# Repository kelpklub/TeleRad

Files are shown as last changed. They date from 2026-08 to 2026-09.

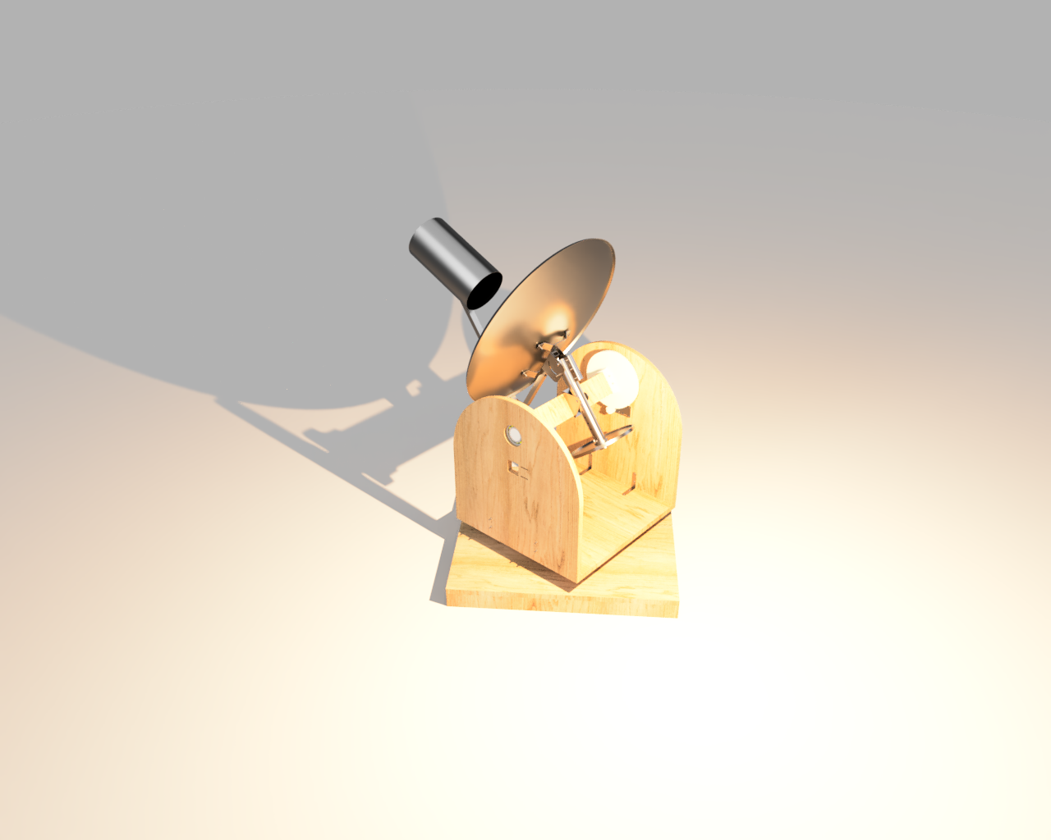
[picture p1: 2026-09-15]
TeleRad-Render.png

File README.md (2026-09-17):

# TeleRad-A radio telescope  
###       
NOTE: This project is currently in its design phase. No physical prototype has been made yet.  
A radio telescope mounted on an two axis alt-azimuth motorized mount for observing radio phenomenon.  
# About TeleRad  
I've always loved stargazing as a kid back in My rural Village . My love for the cosmos hasn't decreased , in fact it has increased manyfold. Alas ! Now i live in the In the Urban Area with light bleeding out every star . Even in my village I cant stargaze anymore.  
But is a few thousand lightbulbs going to stop me from observing the Night sky.  
NO , IT WILL NOT.  
TL;DR- I decided Viewing it in a diffrent ElectroMagnetic Spectrum would prove to be better as theres not as much radio pollution than light pollution. 
# What I Learned  
- Mechanical Design
- Embedded System
- Planning And Designing
- Communication protocol
- Optimizing Costs and Trade-offs
- Will Probs learn More during the building phase.

# Overview 
The Radio telescope will be made up of two systems.  
- Esp32 powered dual axis mount  
 (An Esp32 will control two stepper motors which will motorize two axes of the mount. The mount will move in a snake scan pattern across the sky.)
- Radio reciever  
  (An parabolic satallite ~75cm in diameter dish will will feed signal into a Low Noise Amplifier which goes through a Software Defined Radio dongle into a computer where it will be processed and converten into a 2d image map)  
## Bill of Materials
Heres everything needed for this project. [Bill Of Materials](BOM.csv)  
| Name | Quantity | Per Unit Cost (INR) | Total Cost (INR) | Total Cost (USD) | Link |
|---|---:|---:|---:|---:|---|
| Nema 17 Stepper Motor | 2 | 1109 | 2218 | 23.35 | [Link](https://robu.in/product/42hs60-1684-nema17-7-2kg-cm-stepper-motor-round-type/) |
| Nema 17 Mount Straight | 2 | 201 | 402 | 4.23 | [Link](https://robu.in/product/easymech-bracket-for-nema-17-stepper-motor-2/) |
| DRV8825 Stepper motor driver | 2 | 96 | 192 | 2.02 | [Link](https://robu.in/product/drv8825-stepper-motor-driver-aluminum-heat-sink-good-quality/) |
| 6008 Ball Bearing | 2 | 179 | 358 | 3.77 | [Link](https://www.amazon.in/gp/product/B08LPR978X/ref=ox_sc_act_title_7?smid=A1ATPDR7BUKQN6&th=1) |
| m3 x4mm brass inserts | 4 | 4.4 | 17.6 | 0.2 | [Link](https://onlyscrews.in/products/m3-x-4mm-3d-printing-brass-threaded-inserts-dia-3mm-length-4mm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) |
| m3 x6 mm screws | 14 | 1.2 | 16.8 | 0.18 | [Link](https://onlyscrews.in/products/hex-allen-csk-m3-x-6-screw-pack-of-20?variant=48591246098745) |
| M4 Hex Nut | 37 | - | - | - | Self Funded |
| M4 Bolt 35mm | 14 | - | - | - | Self Funded |
| M4 Bolt 25mm | 4 | - | - | - | Self Funded |
| M4 Bolt 40mm | 2 | - | - | - | Self Funded |
| Limit switches | 2 | 15 | 30 | 0.4 | [Link](https://robu.in/product/limit-switch-kv-05/) |
| 3m USB A to USB A | 1 | 399 | 399 | 4.2 | [Link](https://www.amazon.in/Storite-3-0-Extension-Transfer-Keyboard/dp/B00OFM6PFS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) |
| 22 Gague jumper wire | 2 | 149 | 298 | 3.14 | [Link](https://www.amazon.in/gp/product/B0B4WPX449/ref=ox_sc_act_title_2?smid=AJ6SIZC8YQDZX&psc=1) |
| Coaxial Cable | 1 | 294 | 294 | 3.09 | [Link](https://www.amazon.in/gp/product/B08254RHT3/ref=ox_sc_act_title_6?smid=A3G972E7L8N6MV&psc=1) |
| SMA Edge connector for DIY feed | 1 | 99 | 99 | 1.1 | [Link](https://www.amazon.in/Panel-Straight-Connector-Coaxial-Adapter/dp/B0965PSMSW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) |
| RTL SDR V3 | 1 | 7678 | 7678 | 80.82 | [Link](https://www.amazon.in/gp/product/B0BMKB3L47/ref=ox_sc_act_image_1?smid=A1YZ9MMK17G6RH&th=1) |
| Low Noise Amplifier | 1 | 205 | 205 | 2.16 | [Link](https://robu.in/product/0-1-2000mhz-rf-wideband-amplifier-gain-30db-low-noise-amplifier-lna-board-module/) |
| ESP 32 | 1 | 549 | 549 | 5.78 | [Link](https://www.amazon.in/gp/product/B0D6GDV77P/ref=ox_sc_act_title_4?smid=AJ6SIZC8YQDZX&psc=1) |
| DC-DC 12V-3.3V | 1 | 49 | 49 | 0.52 | [Link](https://robu.in/product/dc-dc-voltage-converter-multi-output-power-supply-module-12v-3-3v5v12v/) |
| 12V 5A powersupply | 1 | 449 | 449 | 4.73 | [Link](https://robu.in/product/orange-ac-100-240v-to-dc-12v-5a-60w-power-adapter/) |
| Perf Board | 2 | 118 | 236 | 2.48 | [Link](https://www.amazon.in/gp/product/B09ZB4W17X/ref=ox_sc_act_title_1?smid=A31PUIOPHJ56Y3&psc=1) |
| 100 uF Capacitors | 5 | 2.36 | 11.8 | 0.2 | [Link](https://robu.in/product/100-uf-35v-through-hole-electrolytic-capacitor-dip-pack-of-10/) |
| 100nF Capacitor | 10 | 1.25 | 12.5 | 0.2 | [Link](https://robu.in/product/100nf-50v-disc-capacitor/) |
| 5x20 Cartridge Fuse 4A | 5 | 36 | 144 | 1.51 | [Link](https://robu.in/product/0239004-mxp-littelfuse-0239004-mxp-fuse-cartridge-time-delay-4-a-125-v-5mm-x-20mm-0-2-x-0-79-slo-blo-239/) |
| 5x20 Cartridge Fuse Holder | 1 | 30 | 30 | 0.31 | [Link](https://robu.in/product/0239004-mxp-littelfuse-0239004-mxp-fuse-cartridge-time-delay-4-a-125-v-5mm-x-20mm-0-2-x-0-79-slo-blo-239/) |
| allen key set | 1 | 200 | 200 | 2.09 | [Link](https://onlyscrews.in/products/allen-key-mm-set-m1-5-to-m10-chrome-vanadium-steel?variant=49975496671545) |
| 3D Prints | 1 | 2867.40 | 2867.40 | 30 | #printing-legion |
| **Total** | | | | **151.11** | |
## CAD  
The Basic Cad design Assembly Of the mount can be found at [TeleRad Assembly](CAD/Components%20STEP/Assembly/Assembly.step)
TeleRad

The Mount utilizes Gears to increase torque.
Screenshot (7)  
## Gears  
### Gear Ratio
The gear Ratios for both axes are as follows :-  
For The Altitude Rotation - Input gear teeth = 16T ; Output gear teeth = 128T  
For The Azimuth  Rotation - Input gear teeth = 24T ; Output gear teeth = 72T  
### 3D printing  
The STL files to be present are int [3D Print STL](CAD/3D%20Print%20STL/)
## Basic Wiring  
The wiring is as follows:-  
TeleRad-Schematic_diagram

**MICROSTEPPING** - The M2 pin of both driver boards are connected to 3.3v of esp32 to set microstepping to 1/16 microstepping following the documentation of the drv8825 board.  
microsteps-drv8825-snip  
**DRV8825 BOARD PROTECTION** - A 100µF Capacitor And 100nF Capacitor are wired across VMOT and GND to stabalize VMOT and Supress high frequency Noise.  
**POWER SUPPLY** - An external powersupply of 12V is required for the two DRV8825 connected to VMOT of both driver.  
## Homing  
At Setup both motots will move in -x and -y direction till the it hits its respective limiting switch. When it does it will Mark that position as origin of that axis.After both axes have been calibrated it will rely on step counting for its current position.  
# Software  
TeleRad consists of two software components  
## ESP32 Firmware- Acts as a Motion Controller.  
It handles 
- Stepper Motor Control.
- Homing.
- Position Tracking.
- Serial Command Processing.
## Python firmware 
- ESP32 Communication
- Mount Control
- SDR control
- Radio Measurments
- Scanning
# Setup  
## Hardware 
- Assemble the Mount.
- uhhh (More Detailed Instructions will be given after i build the mount.)
## Software  
### ESP32  
1.Install Arduino IDE 
2.Install ESP32 Board Support  
3.Install AccelStepper Library for Arduino IDE  
4.Open Firmware/ESP-32/ESP-32.ino in Arduino IDE  
5.Connect ESP32 with a USB data cable.  
6.Compile the .ino and uploAd it to the ESP.  
7.Test The serial connection by sending "PING" using Serial Moniter.  
### Python 
Clone the Repository and install the Python dependencies.  
cd Firmware/python  
pip install -e .  
Verify Installation wit "telerad --help"  
# Usage  
## Python cli  
- Check Mount Status
  ```bash
  telerad mount status
- Check curremt Position
  ```bash
  telerad mount position
- Home Mount
  ```bash
  telerad mount home  
- Move the mount
  ```bash
  telerad mount move 90 45  
- Move Mount relavtive to its current position
  ```bash
  telerad mount rel 10 -5  
- Scan
  ```bash
  telerad scan start --from 20,30 --to 100,60 --step 1 
NOTE: for Scan the coordinates are opposites corners of a rectangle. the bottom-left and top-right.
- Park the mount
  ```bash
  telerad mount park
- Stop the mount
  ```bash
  telerad mount stop
# AI Declaration  
AI helped with creation of the Firmware Of this project.

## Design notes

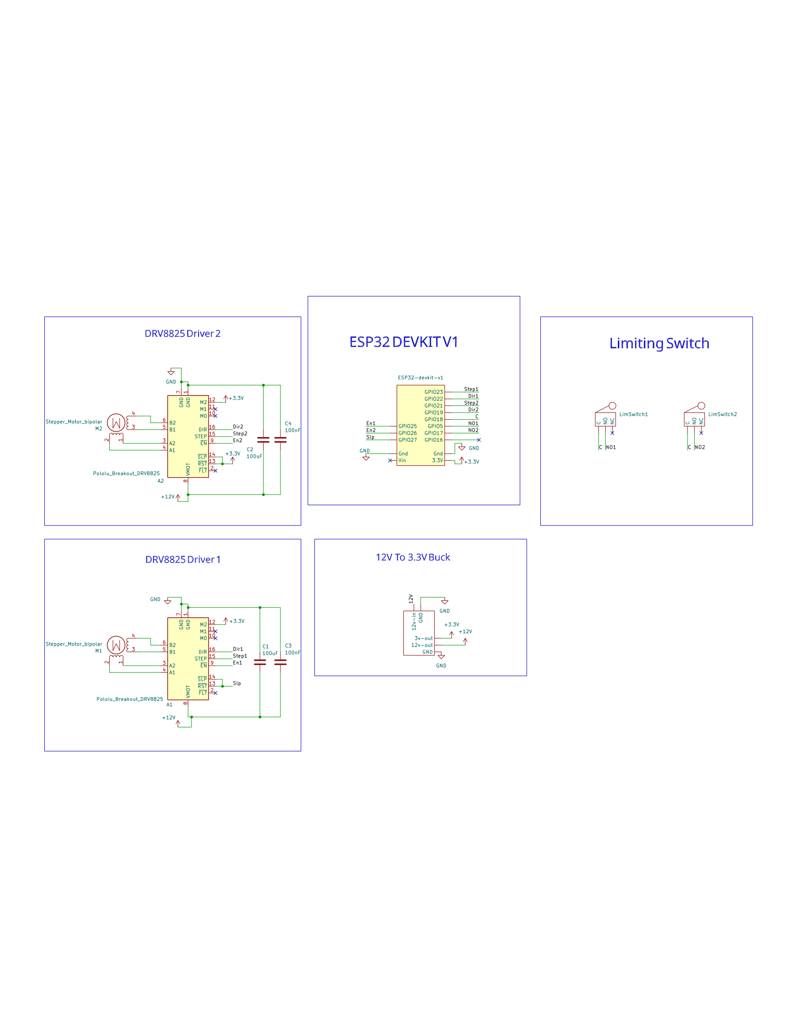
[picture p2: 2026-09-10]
TeleRad-Schematic_diagram.png

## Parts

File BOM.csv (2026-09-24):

Name | Quantity | Per Unit Cost (INR) | Total Cost (INR) | Total Cost (USD) | Link
Nema 17 Stepper Motor | 2 | 1109 | 2218 | 23.35 | https://robu.in/product/42hs60-1684-nema17-7-2kg-cm-stepper-motor-round-type/
Nema 17 Mount Straight | 2 | 201 | 402 | 4.23 | https://robu.in/product/easymech-bracket-for-nema-17-stepper-motor-2/
DRV8825 Stepper motor driver | 2 | 96 | 192 | 2.02 | https://robu.in/product/drv8825-stepper-motor-driver-aluminum-heat-sink-good-quality/
6008 Ball Bearing | 2 | 179 | 358 | 3.77 | https://www.amazon.in/gp/product/B08LPR978X/ref=ox_sc_act_title_7?smid=A1ATPDR7BUKQN6&th=1
m3 x4mm brass inserts | 4 | 4.4 | 17.6 | 0.2 | https://onlyscrews.in/products/m3-x-4mm-3d-printing-brass-threaded-inserts-dia-3mm-length-4mm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
m3 x6 mm screws | 20 | 1.2 | 16.8 | 0.18 | https://onlyscrews.in/products/hex-allen-csk-m3-x-6-screw-pack-of-20?variant=48591246098745
M4 Hex Nut | 37 | - | - | - | Self Funded
M4 Bolt 35mm | 14 | - | - | - | Self Funded
M4 Bolt 25mm | 4 | - | - | - | Self Funded
M4 Bolt 40mm | 2 | - | - | - | Self Funded
Limit switches | 2 | 15 | 30 | 0.4 | https://robu.in/product/limit-switch-kv-05/
3m USB A to USB A | 1 | 399 | 399 | 4.2 | https://www.amazon.in/Storite-3-0-Extension-Transfer-Keyboard/dp/B00OFM6PFS
22 Gague jumper wire | 2 | 149 | 298 | 3.14 | https://www.amazon.in/gp/product/B0B4WPX449/ref=ox_sc_act_title_2?smid=AJ6SIZC8YQDZX&psc=1
Coaxial Cable | 1 | 294 | 294 | 3.09 | https://www.amazon.in/gp/product/B08254RHT3/ref=ox_sc_act_title_6?smid=A3G972E7L8N6MV&psc=1
SMA Edge connector for DIY feed | 1 | 99 | 99 | 1.1 | https://www.amazon.in/Panel-Straight-Connector-Coaxial-Adapter/dp/B0965PSMSW
RTL SDR V3 | 1 | 7678 | 7678 | 80.82 | https://www.amazon.in/gp/product/B0BMKB3L47/ref=ox_sc_act_image_1?smid=A1YZ9MMK17G6RH&th=1
Low Noise Amplifier | 1 | 205 | 205 | 2.16 | https://robu.in/product/0-1-2000mhz-rf-wideband-amplifier-gain-30db-low-noise-amplifier-lna-board-module/
ESP 32 | 1 | 549 | 549 | 5.78 | https://www.amazon.in/gp/product/B0D6GDV77P/ref=ox_sc_act_title_4?smid=AJ6SIZC8YQDZX&psc=1
DC-DC 12V-3.3V | 1 | 49 | 49 | 0.52 | https://robu.in/product/dc-dc-voltage-converter-multi-output-power-supply-module-12v-3-3v5v12v/
12V 5A powersupply | 1 | 449 | 449 | 4.73 | https://robu.in/product/orange-ac-100-240v-to-dc-12v-5a-60w-power-adapter/
Perf Board | 2 | 118 | 236 | 2.48 | https://www.amazon.in/gp/product/B09ZB4W17X/ref=ox_sc_act_title_1?smid=A31PUIOPHJ56Y3&psc=1
100 uF Capacitors | 5 | 2.36 | 11.8 | 0.2 | https://robu.in/product/100-uf-35v-through-hole-electrolytic-capacitor-dip-pack-of-10/
100nF Capacitor | 10 | 1.25 | 12.5 | 0.2 | https://robu.in/product/100nf-50v-disc-capacitor/
5x20 Cartridge Fuse 4A | 5 | 36 | 144 | 1.51 | https://robu.in/product/0239004-mxp-littelfuse-0239004-mxp-fuse-cartridge-time-delay-4-a-125-v-5mm-x-20mm-0-2-x-0-79-slo-blo-239/
5x20 Cartridge Fuse Holder | 1 | 30 | 30 | 0.31 | https://robu.in/product/0239004-mxp-littelfuse-0239004-mxp-fuse-cartridge-time-delay-4-a-125-v-5mm-x-20mm-0-2-x-0-79-slo-blo-239/
allen key set | 1 | 200 | 200 | 2.09 | https://onlyscrews.in/products/allen-key-mm-set-m1-5-to-m10-chrome-vanadium-steel?variant=49975496671545
3D Prints | 1 | 2867.4 | 2867.4 | 30 | -
18 mm Plywood | 1 | 1200 | 1200 | 12.5 | Local Hardware Store
 |  |  |  | 188.98

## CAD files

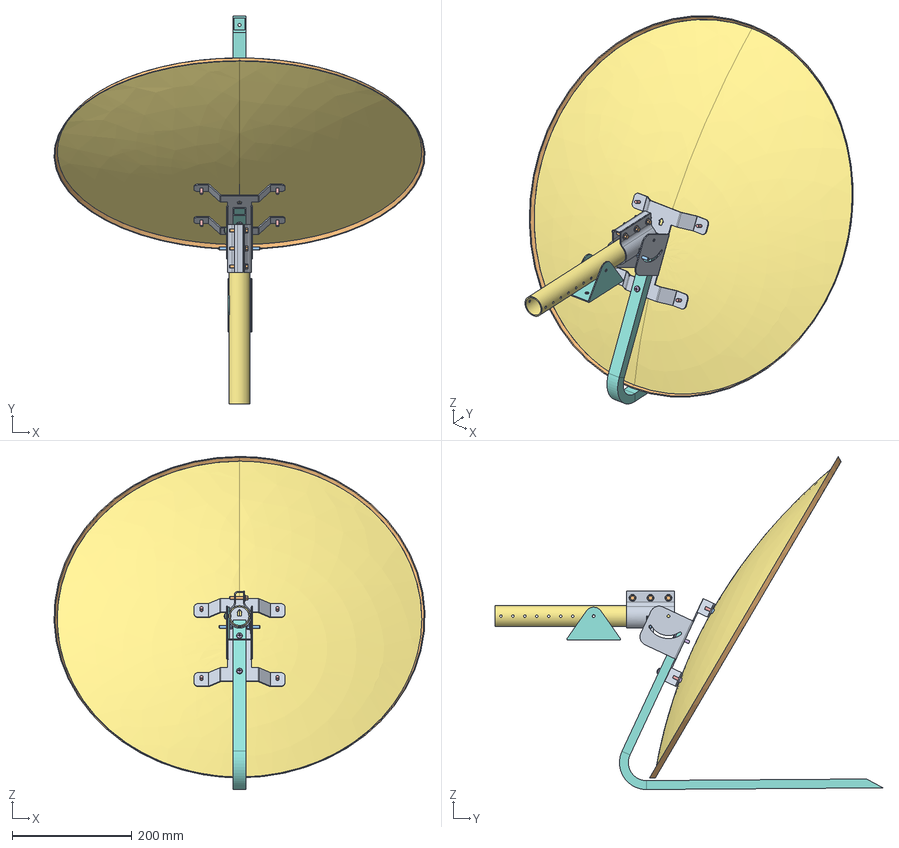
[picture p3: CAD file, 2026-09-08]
CAD/Components STEP/MISC/satellite_assembly.step
620.2 x 648.7 x 556.9 mm
wall_clamp
angle_bracket
dish
main_rod
reciver_rod
support_clamp x 2
tightening_fit
hex flange bolt small_iso_ISO 4162 - M5 x 25 x 25-N x 3
hex flange bolt small_iso_ISO 4162 - M5 x 50 x 50-N x 2
hex flange bolt small_iso_ISO 4162 - M5 x 16 x 16-N x 2
pan head cross recess screw_iso_ISO 7045 - M5 x 8 - Z - 8N
pan head cross recess screw_iso_ISO 7045 - M5 x 16 - Z - 16N x 4
pan head cross recess screw_iso_ISO 7045 - M5 x 25 - Z - 25N x 2
hex flange nut gradea_iso_ISO - 4161 - M5 - N x 13
wall_clamp_1

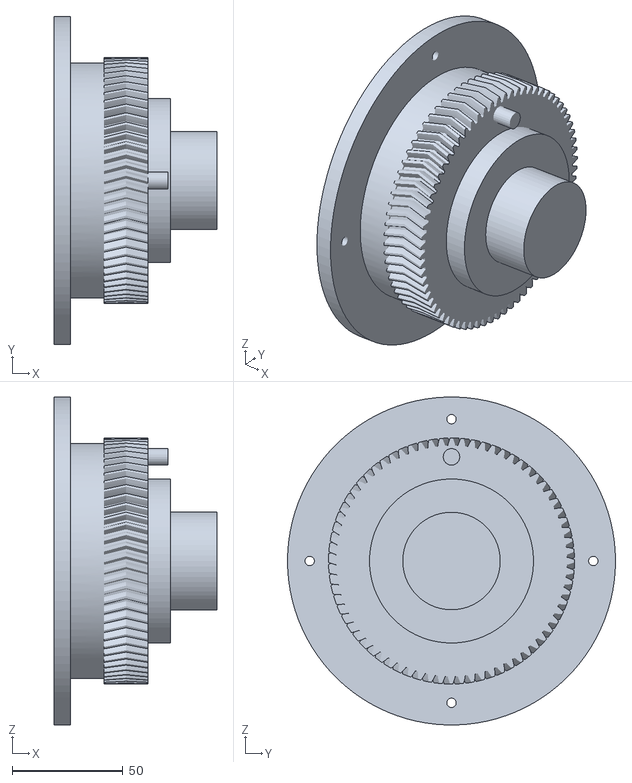
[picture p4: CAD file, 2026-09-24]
CAD/3D Print STL/Azimuth output gear 72T.stl
73.5 x 148.0 x 147.9

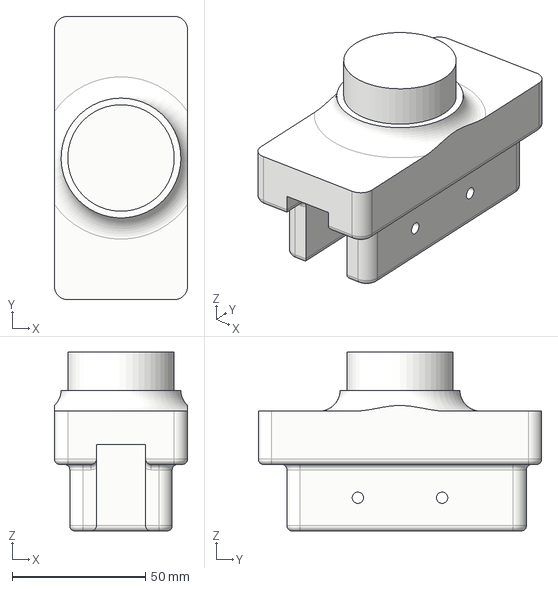
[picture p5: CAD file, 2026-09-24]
CAD/Components STEP/Altitude/Altitude Bearing to plank connector.step
50.0 x 106.5 x 67.2 mm

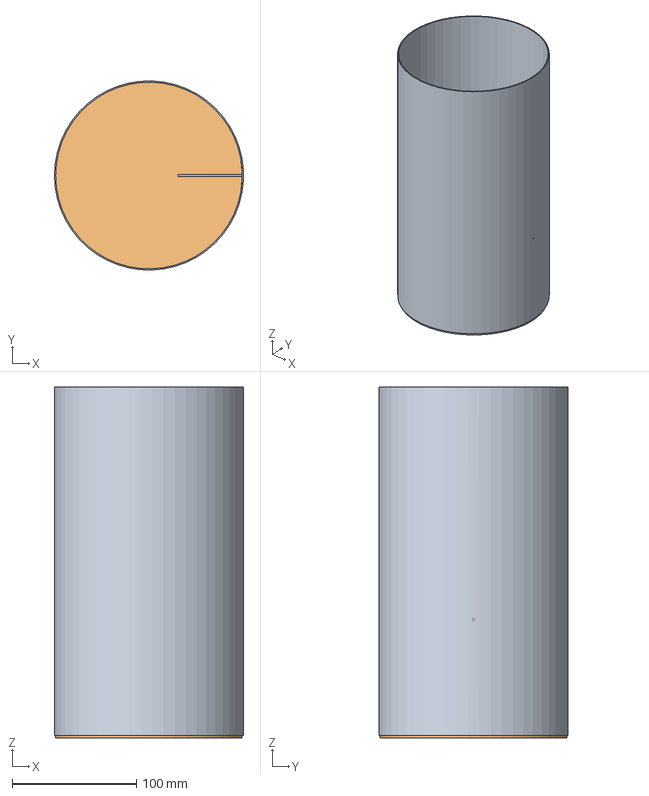
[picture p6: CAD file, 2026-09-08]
CAD/Components STEP/MISC/Caantenna feed.step
152.0 x 151.9 x 282.1 mm

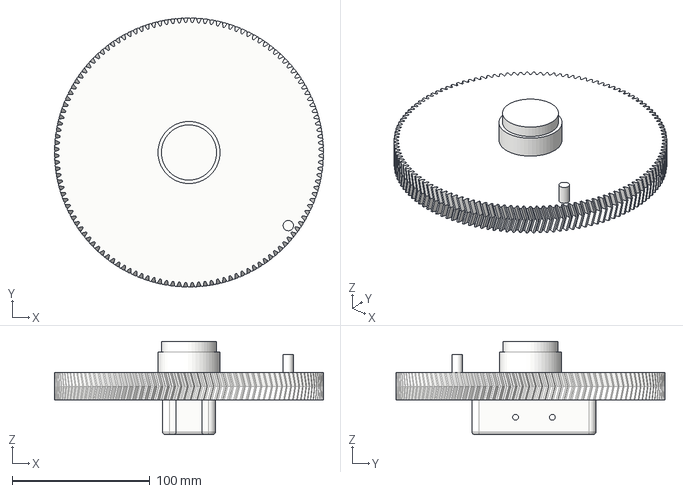
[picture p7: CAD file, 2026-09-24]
CAD/Components STEP/Altitude/Altitude Output gear 128T.step
195.0 x 195.0 x 67.5 mm

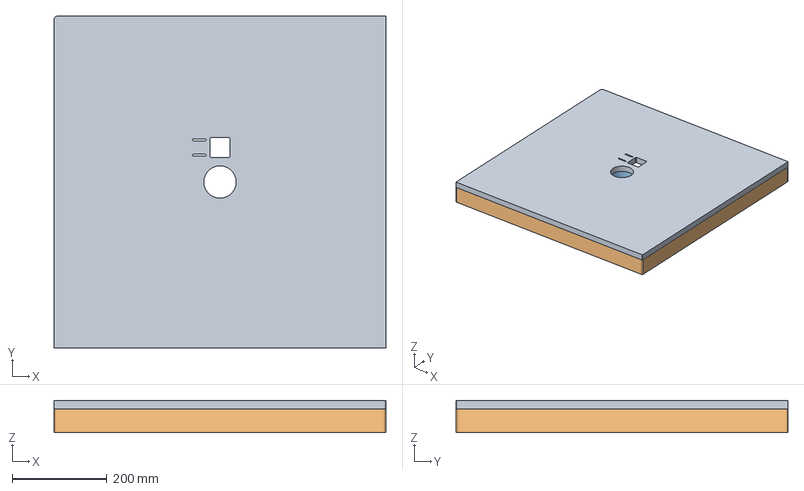
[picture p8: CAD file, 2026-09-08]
CAD/Components STEP/Azimuth/BasePlate.step
700.0 x 700.0 x 68.0 mm

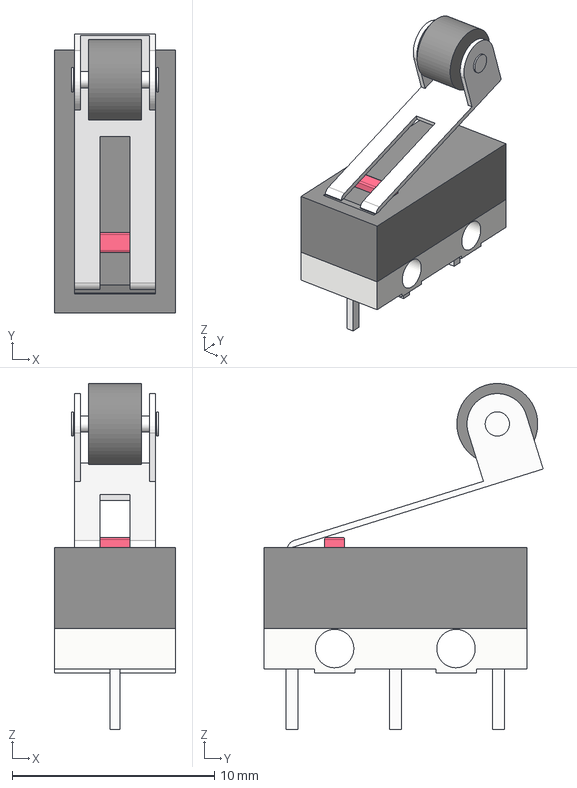
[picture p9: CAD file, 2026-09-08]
CAD/Components STEP/MISC/limit switch.step
6.00 x 13.8 x 17.1 mm

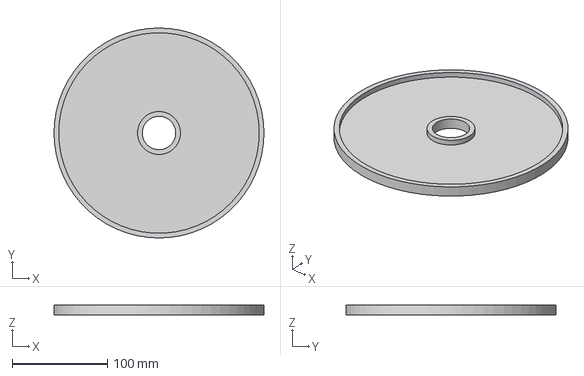
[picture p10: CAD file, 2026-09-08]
CAD/Components STEP/Altitude/Altitude Counterweight.step
220.0 x 220.0 x 10.0 mm

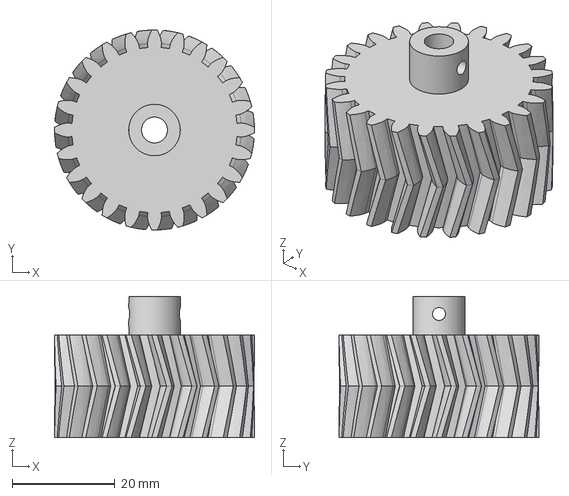
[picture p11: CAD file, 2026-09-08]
CAD/Components STEP/Azimuth/Azimuth input gear 24T.step
39.0 x 39.0 x 27.5 mm

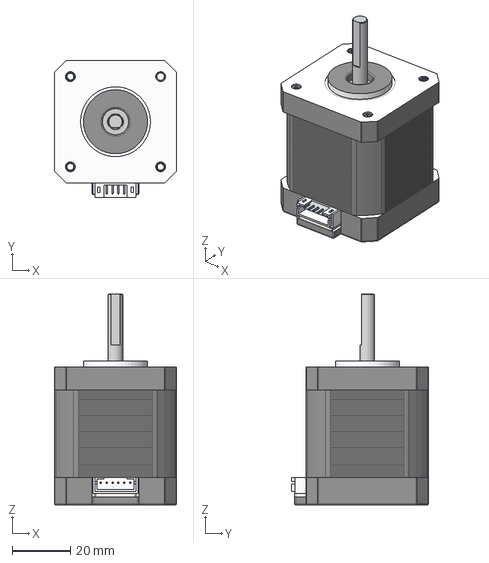
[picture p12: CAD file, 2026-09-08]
CAD/Components STEP/MISC/Nema17.step
42.0 x 47.0 x 72.5 mm
Motor
Shaft

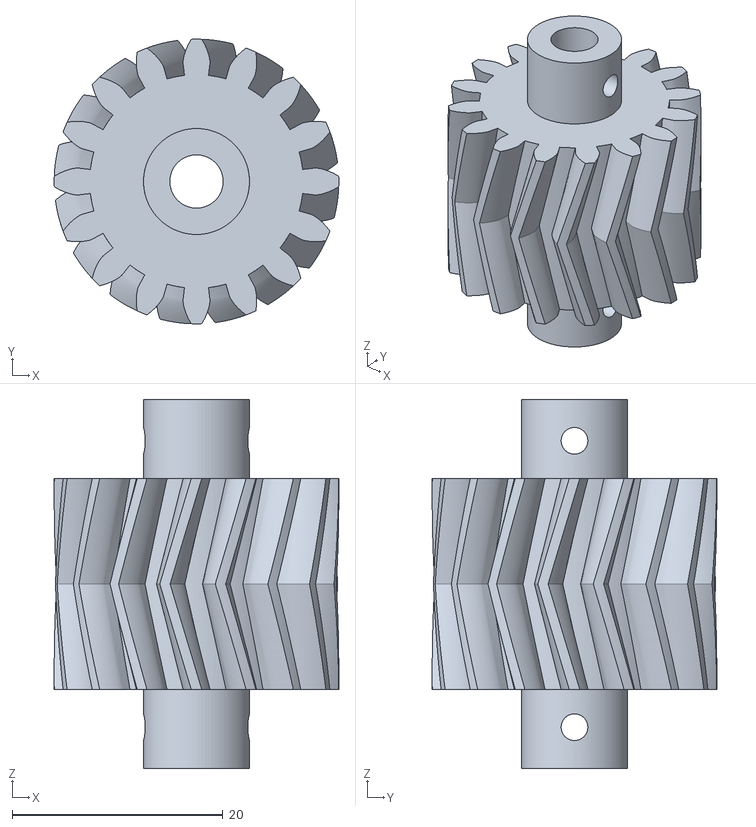
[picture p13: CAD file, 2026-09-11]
CAD/3D Print STL/Altitude Input Gear 16T.stl
27.0 x 27.0 x 35.0

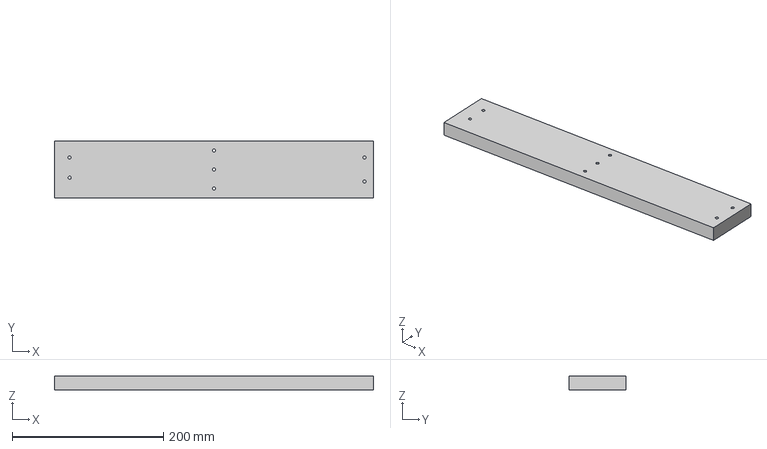
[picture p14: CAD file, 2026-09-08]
CAD/Components STEP/Altitude/Altitude Plank.step
422.0 x 75.0 x 18.0 mm

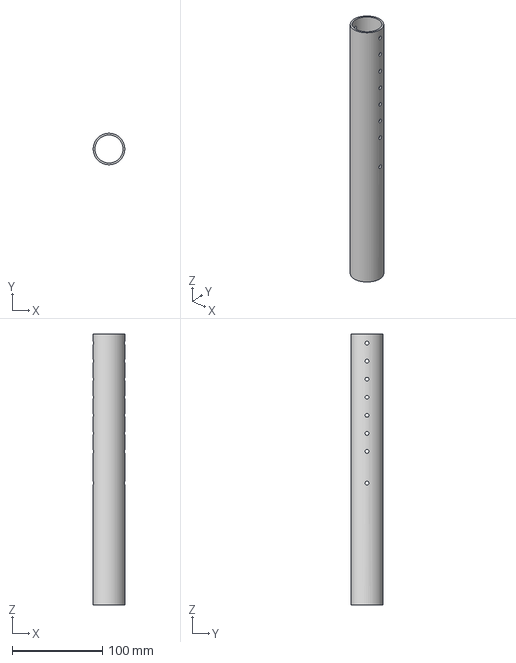
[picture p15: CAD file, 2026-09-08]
CAD/Components STEP/MISC/Satellite mount rod.step
35.0 x 35.0 x 300.0 mm

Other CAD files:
CAD/Components STEP/Azimuth/Azimuth output gear 72T.step
CAD/3D Print STL/Altitude Bearing to plank connector.stl
CAD/3D Print STL/Altitude Output gear 128T.stl
CAD/3D Print STL/Azimuth input gear 24T.stl
CAD/Components STEP/Altitude/Altitude Input Gear 16T.step
CAD/Components STEP/Altitude/Altitude Baseplate.step
CAD/Components STEP/MISC/Nema Mounting Bracket Straight.step

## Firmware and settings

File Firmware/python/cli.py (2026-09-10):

import argparse
import sys

from esp32 import ESP32
from mount import Mount
from scanner import Scanner, print_scan_progress
from measurement import SDR


DEFAULT_PORT = "/dev/ttyUSB0"

class DryRunESP32:
    def connect(self):
        print("[DRY RUN] Connected to simulated ESP32")

    def disconnect(self):
        print("[DRY RUN] Disconnected from simulated ESP32")

    def status(self):
        from esp32 import Status

        return Status(
            state="IDLE",
            azimuth=0,
            altitude=0,
            homed=True,
            enabled=True,
            limit_triggered=False
        )

    def position(self):
        from esp32 import Position

        return Position(
            azimuth=0,
            altitude=0
        )


class DryRunMount:
    def __init__(self):
        self.azimuth = 0.0
        self.altitude = 0.0

    def disconnect(self):
        print("[DRY RUN] Mount disconnected")

    def is_ready(self):
        return True

    def status(self):
        from esp32 import Status

        return Status(
            state="IDLE",
            azimuth=round(self.azimuth),
            altitude=round(self.altitude),
            homed=True,
            enabled=True,
            limit_triggered=False
        )

    def position(self):
        from esp32 import Position

        return Position(
            azimuth=round(self.azimuth),
            altitude=round(self.altitude)
        )

    def home(self):
        print("[DRY RUN] Homing")
        self.azimuth = 0.0
        self.altitude = 0.0

    def move_to_degrees(self, azimuth, altitude):
        print(
            f"[DRY RUN] MOVE "
            f"AZ={azimuth:.2f}° "
            f"ALT={altitude:.2f}°"
        )

        self.azimuth = azimuth
        self.altitude = altitude

    def move_relative_degrees(self, azimuth, altitude):
        self.azimuth += azimuth
        self.altitude += altitude

        print(
            f"[DRY RUN] REL "
            f"AZ={azimuth:.2f}° "
            f"ALT={altitude:.2f}°"
        )

    def park(self):
        print("[DRY RUN] Parking")
        self.azimuth = 0.0
        self.altitude = 0.0

    def stop(self):
        print("[DRY RUN] STOP")

    def emergency_stop(self):
        print("[DRY RUN] ESTOP")

    def clear_emergency_stop(self):
        print("[DRY RUN] CLEAR_ESTOP")


class DryRunSDR:
    def __init__(self, frequency=1420.405e6):
        self.frequency = frequency
        self.connected = False

    def connect(self):
        self.connected = True
        print("[DRY RUN] Connected to simulated SDR")

    def disconnect(self):
        self.connected = False
        print("[DRY RUN] Disconnected from simulated SDR")

    def is_connected(self):
        return self.connected

    def set_frequency(self, frequency):
        self.frequency = frequency

        print(
            f"[DRY RUN] Frequency: "
            f"{frequency / 1e6:.6f} MHz"
        )

    def measure_power(self):
        from measurement import SDRMeasurement

        return SDRMeasurement(
            frequency=self.frequency,
            power_dbfs=-42.0,
            sample_count=16384
        )

def create_parser():
    parser = argparse.ArgumentParser(
        prog="telerad",
        description="TeleRad radio telescope control CLI"
    )

    subparsers = parser.add_subparsers(
        dest="command",
        required=True
    )

    #--dry-run
    parser.add_argument(
    "--dry-run",
    action="store_true",
    help="Simulate hardware without connecting to the ESP32 or SDR (place before the command)"
)

    # Mount

    mount_parser = subparsers.add_parser(
        "mount",
        help="Control the antenna mount"
    )

    mount_subparsers = mount_parser.add_subparsers(
        dest="mount_command",
        required=True
    )

    mount_subparsers.add_parser(
        "status",
        help="Show mount status"
    )

    mount_subparsers.add_parser(
        "position",
        help="Show current mount position"
    )

    mount_subparsers.add_parser(
        "home",
        help="Home the mount"
    )

    move_parser = mount_subparsers.add_parser(
        "move",
        help="Move to an absolute position"
    )

    move_parser.add_argument(
        "azimuth",
        type=float
    )

    move_parser.add_argument(
        "altitude",
        type=float
    )

    rel_parser = mount_subparsers.add_parser(
        "rel",
        help="Move relative to the current position"
    )

    rel_parser.add_argument(
        "azimuth",
        type=float
    )

    rel_parser.add_argument(
        "altitude",
        type=float
    )

    mount_subparsers.add_parser(
        "park",
        help="Park the mount"
    )

    mount_subparsers.add_parser(
        "stop",
        help="Stop normal movement"
    )

    mount_subparsers.add_parser(
        "estop",
        help="Trigger emergency stop"
    )

    mount_subparsers.add_parser(
        "clear-estop",
        help="Clear emergency stop"
    )

    # SDR

    sdr_parser = subparsers.add_parser(
        "sdr",
        help="Control and inspect the SDR"
    )

    sdr_subparsers = sdr_parser.add_subparsers(
        dest="sdr_command",
        required=True
    )

    sdr_subparsers.add_parser(
        "measure",
        help="Measure received signal power"
    )

    frequency_parser = sdr_subparsers.add_parser(
        "frequency",
        help="Set SDR frequency"
    )

    frequency_parser.add_argument(
        "frequency",
        type=float,
        help="Frequency in Hz"
    )

    # Scan

    scan_parser = subparsers.add_parser(
        "scan",
        help="Run radio scans"
    )

    scan_subparsers = scan_parser.add_subparsers(
        dest="scan_command",
        required=True
    )

    scan_start_parser = scan_subparsers.add_parser(
        "start",
        help="Start a scan"
    )

    scan_start_parser.add_argument(
        "--from",
        dest="start",
        type=str,
        required=True,
        metavar="AZ,ALT",
        help="Bottom-left scan coordinate"
    )

    scan_start_parser.add_argument(
        "--to",
        dest="end",
        type=str,
        required=True,
        metavar="AZ,ALT",
        help="Top-right scan coordinate"
    )

    scan_start_parser.add_argument(
        "--step",
        type=float,
        required=True,
        help="Angular spacing between scan positions in degrees"
    )

    scan_start_parser.add_argument(
        "--output",
        default="scan.csv",
        help="CSV output file (default: scan.csv)"
    )

    return parser


def main():
    parser = create_parser()
    args = parser.parse_args()

    if args.dry_run:
        esp32 = DryRunESP32()
        mount = DryRunMount()
    else:
        esp32 = ESP32(DEFAULT_PORT)
        mount = Mount(esp32)

    try:
        if args.command == "mount":
            esp32.connect()
            handle_mount(args, mount)

        elif args.command == "sdr":
            handle_sdr(args, dry_run=args.dry_run)

        elif args.command == "scan":
            esp32.connect()
            handle_scan(args, mount, dry_run=args.dry_run)

    except KeyboardInterrupt:
        print("\nInterrupted.")
        return 130

    except Exception as error:
        print(f"Error: {error}", file=sys.stderr)
        return 1

    finally:
        mount.disconnect()
        if not args.dry_run and args.command in ("mount", "scan"):
            esp32.disconnect()

    return 0


def handle_mount(args, mount):
    if args.mount_command == "status":
        status = mount.status()

        print(f"State: {status.state}")
        print(f"Azimuth: {status.azimuth}°")
        print(f"Altitude: {status.altitude}°")
        print(f"Homed: {'yes' if status.homed else 'no'}")
        print(f"Enabled: {'yes' if status.enabled else 'no'}")
        print(
            f"Limit: {'yes' if status.limit_triggered else 'no'}"
        )

    elif args.mount_command == "position":
        position = mount.position()

        print(f"Azimuth: {position.azimuth}°")
        print(f"Altitude: {position.altitude}°")

    elif args.mount_command == "home":
        print("Homing...")
        mount.home()
        print("Homing complete.")

    elif args.mount_command == "move":
        print(
            f"Moving to "
            f"azimuth {args.azimuth}°, "
            f"altitude {args.altitude}°..."
        )

        mount.move_to_degrees(
            args.azimuth,
            args.altitude
        )

        print("Movement complete.")

    elif args.mount_command == "rel":
        mount.move_relative_degrees(
            args.azimuth,
            args.altitude
        )

        print("Relative movement complete.")

    elif args.mount_command == "park":
        print("Parking...")
        mount.park()
        print("Park complete.")

    elif args.mount_command == "stop":
        mount.stop()
        print("Movement stopped.")

    elif args.mount_command == "estop":
        mount.emergency_stop()
        print("Emergency stop activated.")

    elif args.mount_command == "clear-estop":
        mount.clear_emergency_stop()
        print("Emergency stop cleared.")


def handle_sdr(args, dry_run=False):
    if dry_run:
        sdr = DryRunSDR()
    else:
        sdr = SDR(
            frequency=1420.405e6
        )

    try:
        sdr.connect()

        if args.sdr_command == "frequency":
            sdr.set_frequency(args.frequency)

            print(
                f"Frequency set to "
                f"{args.frequency / 1e6:.6f} MHz"
            )

        elif args.sdr_command == "measure":
            measurement = sdr.measure_power()

            print(
                f"Frequency: "
                f"{measurement.frequency / 1e6:.6f} MHz"
            )

            print(
                f"Power: "
                f"{measurement.power_dbfs:.2f} dBFS"
            )

            print(
                f"Samples: "
                f"{measurement.sample_count}"
            )

    finally:
        sdr.disconnect()


def parse_coordinate(value, name):
    """Parse an AZ,ALT command-line coordinate."""
    parts = value.split(",")

    if len(parts) != 2:
        raise ValueError(
            f"{name} must be in the form AZ,ALT (example: 20,30)"
        )

    try:
        return float(parts[0]), float(parts[1])
    except ValueError as error:
        raise ValueError(
            f"{name} must contain numeric AZ and ALT values"
        ) from error


def handle_scan(args, mount, dry_run=False):
    start_az, start_alt = parse_coordinate(args.start, "--from")
    end_az, end_alt = parse_coordinate(args.end, "--to")

    if dry_run:
        sdr = DryRunSDR()
    else:
        sdr = SDR(
            frequency=1420.405e6
        )

    scanner = Scanner(
        mount=mount,
        sdr=sdr,
        az_start=start_az,
        az_end=end_az,
        alt_start=start_alt,
        alt_end=end_alt,
        step=args.step
    )

    scanner.set_progress_callback(print_scan_progress)

    print(
        f"Starting scan: "
        f"({start_az:.2f}°, {start_alt:.2f}°) → "
        f"({end_az:.2f}°, {end_alt:.2f}°)"
    )

    results = scanner.scan()
    scanner.save_csv(args.output)

    print(f"Scan complete: {len(results)} measurements")
    print(f"Saved: {args.output}")


if __name__ == "__main__":
    sys.exit(main())

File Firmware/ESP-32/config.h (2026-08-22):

#ifndef CONFIG_H
#define CONFIG_H

// Serial

constexpr unsigned long BAUD_RATE = 115200;

// Motion

constexpr float DEFAULT_MAX_SPEED = 1000.0f;
constexpr float DEFAULT_ACCELERATION = 500.0f;

//homing
constexpr float HOMING_ACCELERATION=200.0f;
constexpr long HOMING_SEARCH_DISTANCE=50000;
constexpr unsigned long HOMING_TIMEOUT=60000;

constexpr float HOMING_SPEED_FAST = 400.0f;
constexpr float HOMING_SPEED_SLOW = 100.0f;
constexpr long HOME_OFFSET_STEPS = 200;

// Step Conversion

constexpr float AZ_STEPS_PER_DEGREE = 53.333f;
constexpr float ALT_STEPS_PER_DEGREE = 106.667f;

// Limits

constexpr long AZ_MIN_STEPS = 0;
constexpr long AZ_MAX_STEPS = 19200;

constexpr long ALT_MIN_STEPS = 0;
constexpr long ALT_MAX_STEPS = 9600;



//parking pos
constexpr long PARK_AZIMUTH_STEPS=0;
constexpr long PARK_ALTITUDE_STEPS=0;

// Timeouts (ms)

constexpr unsigned long COMMAND_TIMEOUT = 3000;
constexpr unsigned long STATUS_INTERVAL = 500;

// Safety

constexpr bool ENABLE_SOFT_LIMITS = true;
constexpr bool ENABLE_LIMIT_SWITCHES = true;

#endif

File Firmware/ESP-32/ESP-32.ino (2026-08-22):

#include "config.h"
#include "Motion.h"
#include "Safety.h"
#include "Homing.h"
#include "Logger.h"
#include "SerialProtocol.h"
#include "ConfigStorage.h"

void setup()
{
    Serial.begin(BAUD_RATE);
    initLogger();
    initConfigStorage();

    loadConfig();

    initMotion();

    setSpeed(getStoredSpeed());
    setAcceleration(getStoredAcceleration());
    
    initSafety();
    initHoming();
    initSerialProtocol();
}

void loop()
{
    updateMotion();
    updateHoming();
    updateSafety();
    updateSerialProtocol();
}

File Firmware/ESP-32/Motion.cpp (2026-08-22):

#include "Motion.h"
#include <AccelStepper.h>

//motor obj
AccelStepper azMotor(
    AccelStepper::DRIVER,
    AZ_STEP_PIN,
    AZ_DIR_PIN
);
AccelStepper altMotor(
    AccelStepper::DRIVER,
    ALT_STEP_PIN,
    ALT_DIR_PIN
);


//state
static Position currentPosition = {0, 0};
static Position targetPosition={0,0};
static MotionState motionState =MotionState::IDLE;
static bool motorsEnabled = false;
static float currentSpeed= DEFAULT_MAX_SPEED;
static float currentAcceleration=DEFAULT_ACCELERATION;

//INITIALIZATION
void initMotion()
{
    pinMode(AZ_ENABLE_PIN,OUTPUT);
    pinMode(ALT_ENABLE_PIN,OUTPUT);

    disableDrivers();

    azMotor.setMaxSpeed(currentSpeed);
    azMotor.setAcceleration(currentAcceleration);

    altMotor.setMaxSpeed(currentSpeed);
    altMotor.setAcceleration(currentAcceleration);

    azMotor.setCurrentPosition(0);
    altMotor.setCurrentPosition(0);

    currentPosition.azimuth=0;
    currentPosition.altitude=0;

    targetPosition=currentPosition;
    motionState=MotionState::IDLE;
}

//driver control 
void enableDrivers()
{
    digitalWrite(AZ_ENABLE_PIN,LOW);
    digitalWrite(ALT_ENABLE_PIN,LOW);
    motorsEnabled=true;
}

void disableDrivers()
{
    digitalWrite(AZ_ENABLE_PIN,HIGH);
    digitalWrite(ALT_ENABLE_PIN,HIGH);
    motorsEnabled=false;
}

bool driversEnabled()
{
    return motorsEnabled;
}

//motor settings
void setSpeed(float speed)
{
    currentSpeed=speed;
    azMotor.setMaxSpeed(speed);
    altMotor.setMaxSpeed(speed);
}

void setAcceleration(float acceleration)
{
    currentAcceleration=acceleration;
    azMotor.setAcceleration(acceleration);
    altMotor.setAcceleration(acceleration);
}

float getSpeed()
{
    return currentSpeed;
}

float getAcceleration()
{
    return currentAcceleration;
}

//movement
void moveTo(long azimuthSteps, long altitudeSteps)
{
    if(!motorsEnabled)
    {
        enableDrivers();
    }
    targetPosition.azimuth=azimuthSteps;
    targetPosition.altitude=altitudeSteps;

    azMotor.moveTo(azimuthSteps);
    altMotor.moveTo(altitudeSteps);
    motionState=MotionState::MOVING;
}

void moveRelative(long azimuthOffset,long altitudeOffset)
{
    moveTo(currentPosition.azimuth+azimuthOffset,currentPosition.altitude+altitudeOffset);
}

void park()
{
    moveTo(PARK_AZIMUTH_STEPS,PARK_ALTITUDE_STEPS);
    motionState=MotionState::PARKING;
}

void stopMotion()
{
    azMotor.stop();
    altMotor.stop();
    motionState=MotionState::STOPPED;
}

void stopAzimuth()
{
    azMotor.stop();
}

void stopAltitude()
{
    altMotor.stop();
}

//motion state
bool isBusy()
{
    return(azMotor.distanceToGo()!=0 || altMotor.distanceToGo()!=0);
}

MotionState getMotionState()
{
    return motionState;
}

//Motion 
void updateMotion()
{
    azMotor.run();
    altMotor.run();

    currentPosition.azimuth=azMotor.currentPosition();
    currentPosition.altitude=altMotor.currentPosition();

    switch (motionState)
    {
        case MotionState::MOVING:
        case MotionState::PARKING:
            if (!isBusy())
            {
                motionState=MotionState::IDLE;
            }
            break;
        case MotionState::STOPPED:
            if (!isBusy())
            {
            motionState=MotionState::IDLE;
            }
            break;
        case MotionState::IDLE:
        case MotionState::HOMING:
        case MotionState::ERROR:
        break;
    }
}

void setMotionState(MotionState state)
{
    motionState = state;
}

//position
Position getCurrentPosition()
{
    return currentPosition;
}

Position getTargetPosition()
{
    return targetPosition;
}

void setCurrentPosition(long azimuth,long altitude)
{
    azMotor.setCurrentPosition(azimuth);
    altMotor.setCurrentPosition(altitude);
    currentPosition.azimuth=azimuth;
    currentPosition.altitude=altitude;
    targetPosition=currentPosition;
}

void zeroPosition()
{
    setCurrentPosition(0,0);
}

//coordinate conversion
long azimuthDegreesToSteps(float degrees)
{
    return (long)(degrees*AZ_STEPS_PER_DEGREE);
}

long altitudeDegreesToSteps(float degrees)
{
    return (long) (degrees*ALT_STEPS_PER_DEGREE);
}

float azimuthStepsToDegrees(long steps)
{
    return (float)(steps/AZ_STEPS_PER_DEGREE);
}

float altitudeStepsToDegrees(long steps)
{
    return (float) (steps/ALT_STEPS_PER_DEGREE);
}

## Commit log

2026-05-10 added basic esp32 sketch that creates a webpage,renames directories to remove spaces,added a firmware directory
2026-05-11 updated the webpage that the esp32 will host
2026-05-16 esp32 sketch update-Done with everything i can rn
2026-05-27 Added Limiting switches in assembly
2026-05-30 Added wiring for Limiting Switches,remved MPU9250
    [TeleRad.kicad_sch]
2026-05-30 updated kicad schematic image
2026-05-30 Revise README wiring details
    Updated the description of the mount's scanning pattern, added limiting switches to the wiring section, and corrected the number of components. Also added a new section for coordinate calibration.
2026-07-29 Reworked the code for esp32
    [ESP-32.ino]
2026-07-30 ESP32 code fix2
2026-07-31 Added motion header and did config and init of motors
2026-07-31 finishe motor init
2026-08-04 fixed logic issues in safety and started implementing homing
    [Safety.cpp]
2026-08-05 Add project badges to README
    Added badges for ESP32 compatibility, RTL-SDR support, project status, and last commit date.
2026-09-02 BOM update
    [BOM.csv]
2026-09-07 Add detailed bill of materials to README
    Updated the README to include a detailed bill of materials with links and costs for each component.
2026-09-08 CAD Update
    [Altitude Baseplate.step, Altitude Bearing to plank connector.step, Altitude Counterweight.step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]
2026-09-10 Update BOM.csv with new fuse components
    Added 5x20 Cartridge Fuse and Fuse Holder to BOM.
    [BOM.csv]
2026-09-10 Fix price formatting for 5x20 Cartridge Fuse
    Corrected the pricing format for the 5x20 Cartridge Fuse.
    [BOM.csv]
2026-09-10 Schematic update
    [TeleRad.kicad_sch]
2026-09-10 Removed clones of schematic diagram
2026-09-10 Update README with ESP32 setup and fix typos
    Added installation instructions for ESP32 and corrected typos.
2026-09-10 Update README with AI declaration and command format
    Add AI declaration to README and format mount stop command
2026-09-11 Organized CAD Folders
    [Altitude Baseplate.step, Altitude Bearing to plank connector.step, Altitude Bearing to plank connector.stl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]
2026-09-17 ReStructured CAD folder
    [Altitude Baseplate.step, Altitude Bearing to plank connector.step, Altitude Counterweight.step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]
2026-09-24 Strengthened walls for 3d printing
    [Altitude Bearing to plank connector.step, Altitude Bearing to plank connector.stl, Altitude Output gear 128T.step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]
2026-09-24 Update BOM.csv
    Removed the URL for the 3D Prints entry in BOM.csv.
    [BOM.csv]
